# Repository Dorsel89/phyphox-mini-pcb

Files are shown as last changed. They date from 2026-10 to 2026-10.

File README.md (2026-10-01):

# phyphox:mini – PCB

KiCad project for the **phyphox:mini**, a small Bluetooth LE sensor board that
streams its measurements to the [phyphox](https://phyphox.org) app.

The design files were created with **KiCad 10**. Older KiCad versions cannot
open them.

## Hardware

| Part | Function |
|---|---|
| Nordic **nRF52832** (QFN48) | MCU with Bluetooth LE, internal DC/DC converter |
| ST **LSM6DSR** | accelerometer and gyroscope |
| Bosch **BMP580** | air pressure and temperature |
| TI **HDC1080** | relative humidity and temperature |
| Sensirion **STCC4** | CO₂ |
| Renesas/Adesto **AT25FF161A** | 16 Mbit (2 MB) SPI flash for data logging and firmware updates |
| 32 MHz and 32.768 kHz crystals | radio clock and low-power real-time clock |
| PCB antenna | 2.4 GHz, after TI application note SWRA117D |
| LED, test pads | status LED, programming and debugging (SWD) |

- 4-layer board, about 20 × 30 mm
- IMU and flash are connected via SPI; pressure, humidity and CO₂ sensors
  share one I²C bus.

## Files

| Path | Content |
|---|---|
| `Keyfob_2025_nrf52832.kicad_pro` | KiCad project |
| `Keyfob_2025_nrf52832.kicad_sch` | schematic |
| `Keyfob_2025_nrf52832.kicad_pcb` | board layout |
| `lib/` | project symbols (`*.kicad_sym`), footprints (`phyphox-footprints.pretty`) and 3D models (`3d/`) |

The project libraries are referenced relative to the project directory
(`sym-lib-table`, `fp-lib-table`), so the project opens without further setup.

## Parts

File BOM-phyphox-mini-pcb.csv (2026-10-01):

Reference | Value | Footprint | Qty | DNP | Digikey | Hersteller-Teilenummer | JLC Part | Manufacturer Part
C1 | 47uF | Capacitor_SMD:C_0805_2012Metric | 1 |  |  |  | C16780 | CL21A476MQYNNNE
C2,L1 | nc | Capacitor_SMD:C_0402_1005Metric,Inductor_SMD:L_0402_1005Metric | 2
C3,C4,C12,C13 | 12pF | Capacitor_SMD:C_0402_1005Metric | 4 |  |  |  | C526985 | CC0402GRNPO9BN120
C5,C9,C11,C14,C15 | 100nF | Capacitor_SMD:C_0402_1005Metric | 5 |  | 1276-6720-1-ND |  | C1525 | CL05B104KA5NNNC
C6 | 0.8pF NP0 5% | Capacitor_SMD:C_0402_1005Metric | 1
C7 | 4.7uF | Capacitor_SMD:C_0402_1005Metric | 1 |  | 1276-1784-1-ND |  | C23733 | CL05A475KP5NRNC
C8 | 100pF | Capacitor_SMD:C_0402_1005Metric | 1 |  | 478-1082-1-ND |  | C1546 | KGM05ACG1H101FN
C10 | 1uF | Capacitor_SMD:C_0402_1005Metric | 1 |  | 1276-1067-1-ND |  | C52923 | CL05A105KO5NNNC
C16 | 0.5pF | Capacitor_SMD:C_0402_1005Metric | 1
D1 | LED | LED_SMD:LED_0402_1005Metric | 1
L3 | 3.9nH | Inductor_SMD:L_0402_1005Metric | 1 |  |  |  | C14033 | MLG1005S3N9BT000
L4 | 15nH | Inductor_SMD:L_0402_1005Metric | 1 |  |  |  | C27143 | MLG1005S15NJT000
L5 | 10uH | Inductor_SMD:L_0603_1608Metric | 1 |  |  |  | C1035 | MLF1608E100KTD00
R1 | 1R1 | Resistor_SMD:R_0402_1005Metric | 1 |  |  |  |  | SFR01MZPJ112
R2,R3,R4,R5 | 10k | Resistor_SMD:R_0402_1005Metric | 4 |  |  |  |  | RCA040210K0JNED
TP1 | TestPoint | phyphox-footprints:MY-ZJ-128 | 1
TP5 | TestPoint | phyphox-footprints:phyfob_bat_dot | 1 | Nicht bestücken
U1 | nRF52832-QFxx | Package_DFN_QFN:QFN-48-1EP_6x6mm_P0.4mm_EP4.6x4.6mm | 1
U2 | LSM6DSRTR | phyphox-footprints:lsm6dsr | 1
U3 | BMP580 | phyphox-footprints:BMP581 | 1
U4 | HDC1080 | Package_SON:Texas_PWSON-N6 | 1
U5 | STCC4 | phyphox-footprints:STCC4 | 1
U6 | AT25FF161A | phyphox-footprints:USON-8L-2X3X0P6_MAC | 1 |  |  | MX25R1635FZUIL0
Y1 | 32MHz | Crystal:Crystal_SMD_2016-4Pin_2.0x1.6mm | 1 |  |  |  | C718072 | X201632MKB4SI
Y2 | C5185312 | Crystal:Crystal_SMD_3215-2Pin_3.2x1.5mm | 1 |  |  | C5185312

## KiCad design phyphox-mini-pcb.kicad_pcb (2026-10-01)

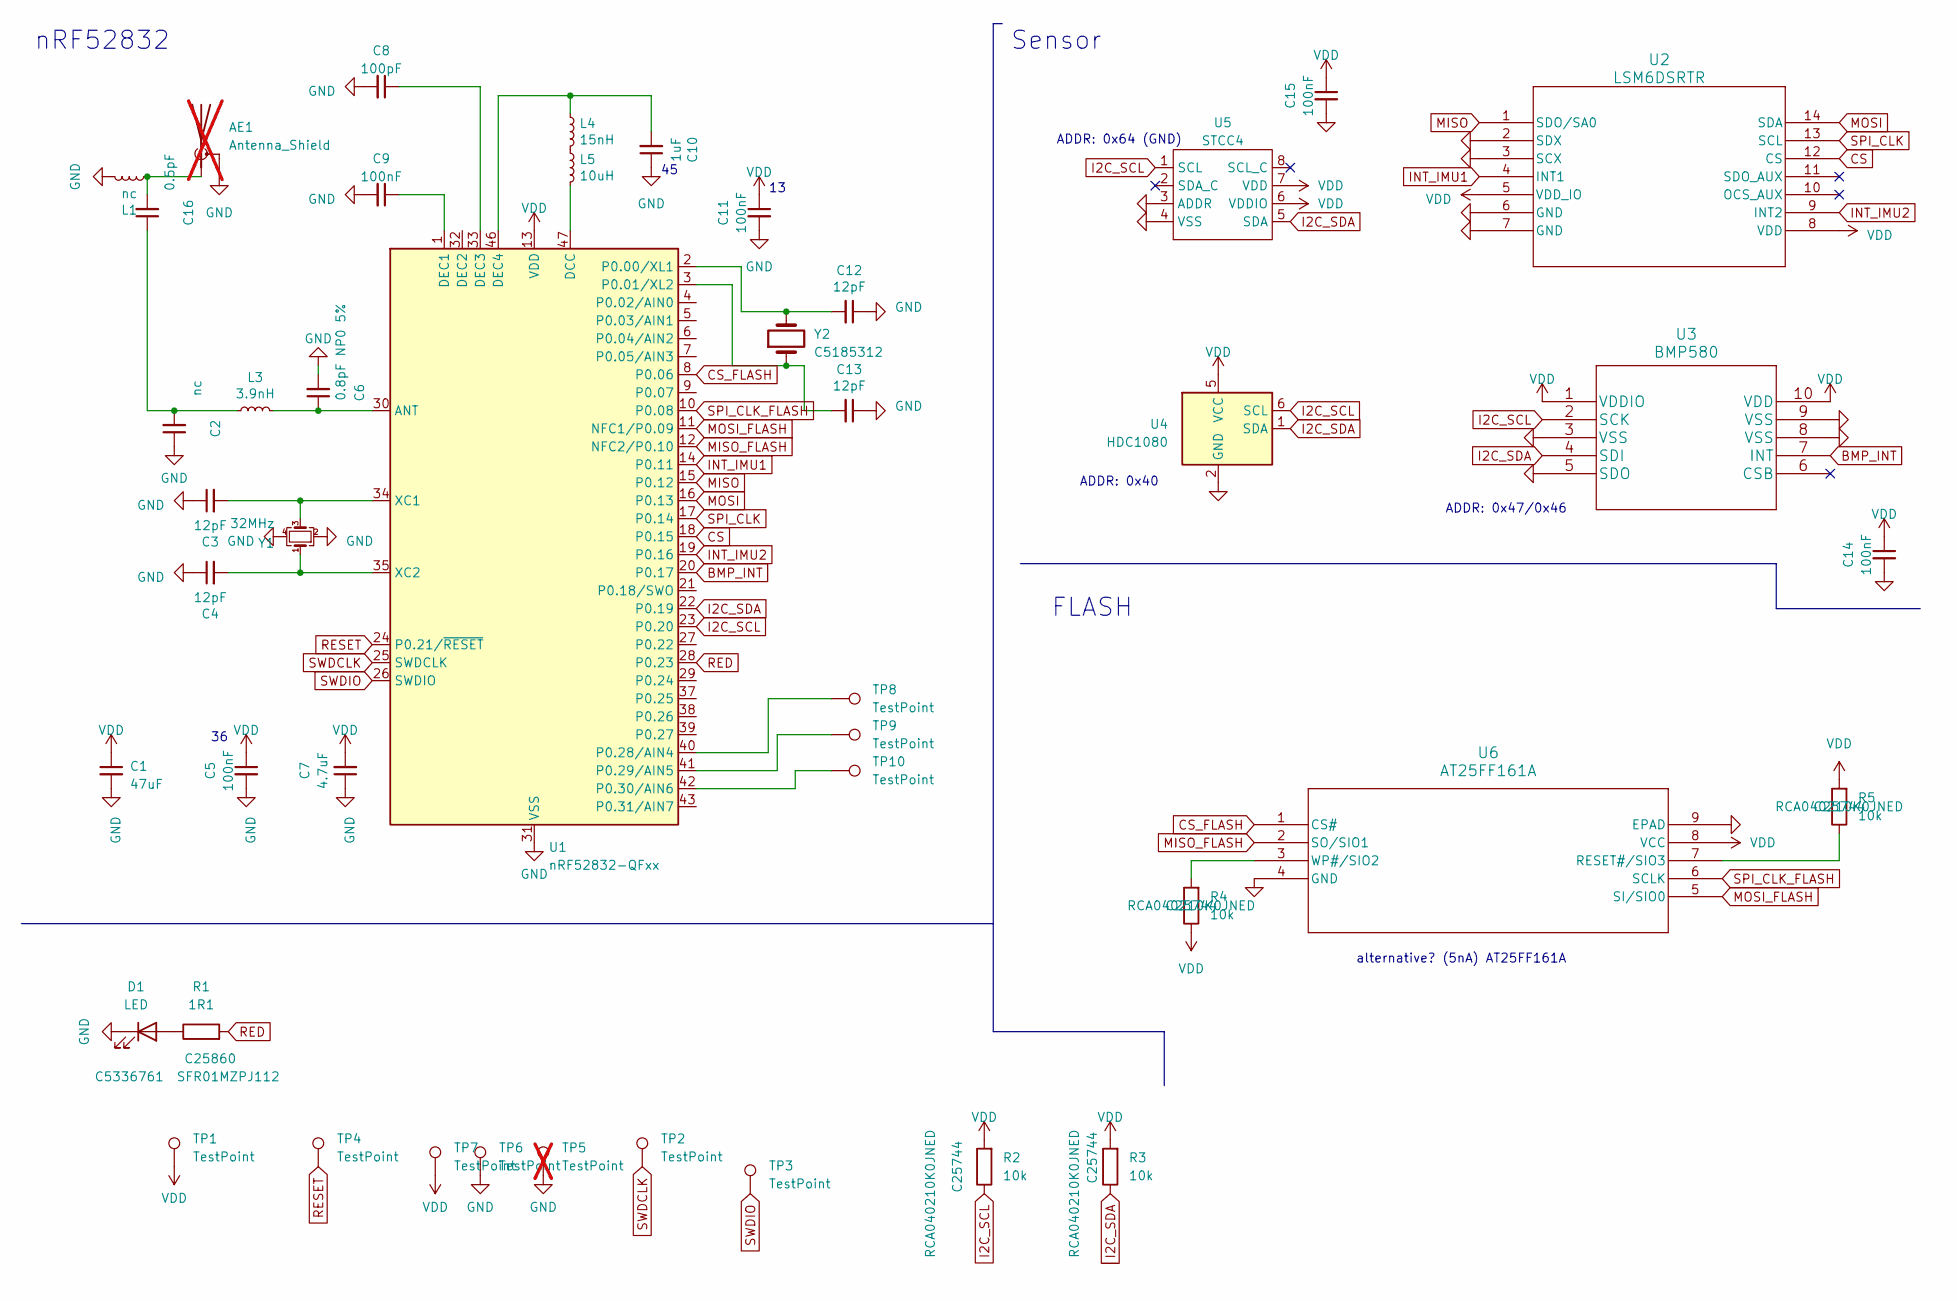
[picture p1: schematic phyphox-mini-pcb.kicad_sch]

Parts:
AE1: Antenna_Shield; Texas_SWRA117D_2.4GHz_Right; not fitted
C1: 47uF; C_0805_2012Metric; Manufacturer Part CL21A476MQYNNNE; LCSC Part C16780
C2: nc; C_0402_1005Metric
C3, C4, C12, C13: 12pF; C_0402_1005Metric; Manufacturer Part CC0402GRNPO9BN120; LCSC Part C526985
C5, C9, C11, C14, C15: 100nF; C_0402_1005Metric; Manufacturer Part CL05B104KA5NNNC; LCSC Part C307331
C6: 0.8pF NP0 5%; C_0402_1005Metric; LCSC Part C76915
C7: 4.7uF; C_0402_1005Metric; Manufacturer Part CL05A475KP5NRNC; LCSC Part C23733
C8: 100pF; C_0402_1005Metric; Manufacturer Part KGM05ACG1H101FN; LCSC Part C1546
C10: 1uF; C_0402_1005Metric; Manufacturer Part CL05A105KO5NNNC; LCSC Part C52923
C16: 0.5pF; C_0402_1005Metric; LCSC C76912
D1: LED; LED_0402_1005Metric; LCSC C5336761
L1: nc; L_0402_1005Metric
L3: 3.9nH; L_0402_1005Metric; Manufacturer Part MLG1005S3N9BT000; LCSC Part C14033
L4: 15nH; L_0402_1005Metric; Manufacturer Part MLG1005S15NJT000; LCSC Part C27143
L5: 10uH; L_0603_1608Metric; Manufacturer Part MLF1608E100KTD00; LCSC Part C1035
R1: 1R1; R_0402_1005Metric; Manufacturer Part SFR01MZPJ112; LCSC C25860
R2, R3, R4, R5: 10k; R_0402_1005Metric; Manufacturer Part RCA040210K0JNED; LCSC C25744
TP1: TestPoint; MY-ZJ-128; LCSC C5354946
TP2, TP3, TP4, TP6, TP7, TP8, TP9, TP10: TestPoint; TestPoint_Pad_D1.0mm
TP5: TestPoint; phyfob_bat_dot; not fitted
U1: nRF52832-QFxx; QFN-48-1EP_6x6mm_P0.4mm_EP4.6x4.6mm; LCSC Part C77540
U2: LSM6DSRTR; lsm6dsr; LCSC Part C784817
U3: BMP580; BMP581; LCSC Part C22391138
U4: HDC1080; Texas_PWSON-N6; LCSC Part C2864159
U5: STCC4; LCSC C49191471
U6: AT25FF161A; USON-8L-2X3X0P6_MAC; LCSC C152595
Y1: 32MHz; Crystal_SMD_2016-4Pin_2.0x1.6mm; Manufacturer Part X201632MKB4SI; LCSC Part C718072
Y2: C5185312; Crystal_SMD_3215-2Pin_3.2x1.5mm; LCSC Part C5185312

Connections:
BMP_INT: U1.20 (P0.17), U3.7 (INT)
CS: U1.18 (P0.15), U2.12 (CS)
CS_FLASH: U1.8 (P0.06), U6.1 (CS#)
GND: AE1.2 (Shield), C1.2, C2.1, C3.1, C4.1, C5.2, C6.2, C7.1, C8.2, C9.2, C10.1, C11.2, C12.1, C13.1, C14.2, C15.2, D1.1 (K), L1.2, TP5.1 (1_1), TP6.1 (1_1), U1.31 (VSS), U1.45 (VSS), U1.49 (VSS), U2.2 (SDX), U2.3 (SCX), U2.6 (GND), U2.7 (GND), U3.3 (VSS), U3.5 (SDO), U3.8 (VSS), U3.9 (VSS), U4.2 (GND), U5.3 (ADDR), U5.4 (VSS), U6.4 (GND), U6.9 (EPAD), Y1.2, Y1.4
I2C_SCL: R2.1, U1.23 (P0.20), U3.2 (SCK), U4.6 (SCL), U5.1 (SCL)
I2C_SDA: R3.1, U1.22 (P0.19), U3.4 (SDI), U4.1 (SDA), U5.5 (SDA)
INT_IMU1: U1.14 (P0.11), U2.4 (INT1)
INT_IMU2: U1.19 (P0.16), U2.9 (INT2)
MISO: U1.15 (P0.12), U2.1 (SDO/SA0)
MISO_FLASH: U1.12 (NFC2/P0.10), U6.2 (SO/SIO1)
MOSI: U1.16 (P0.13), U2.14 (SDA)
MOSI_FLASH: U1.11 (NFC1/P0.09), U6.5 (SI/SIO0)
unnamed: AE1.1 (A), C16.2, L1.1
unnamed: C2.2, C16.1, L3.1
unnamed: D1.2 (A), R1.1
unnamed: L4.2, L5.1
unnamed: C6.1, L3.2, U1.30 (ANT)
unnamed: L5.2, U1.47 (DCC)
unnamed: C9.1, U1.1 (DEC1)
unnamed: C8.1, U1.33 (DEC3)
unnamed: C10.2, L4.1, U1.46 (DEC4)
unnamed: C12.2, U1.2 (P0.00/XL1), Y2.2
unnamed: C13.2, U1.3 (P0.01/XL2), Y2.1
unnamed: TP8.1 (1_1), U1.40 (P0.28/AIN4)
unnamed: TP9.1 (1_1), U1.41 (P0.29/AIN5)
unnamed: TP10.1 (1_1), U1.42 (P0.30/AIN6)
unnamed: C3.2, U1.34 (XC1), Y1.3
unnamed: C4.2, U1.35 (XC2), Y1.1
unnamed: R5.1, U6.7 (RESET#/SIO3)
unnamed: R4.2, U6.3 (WP#/SIO2)
RED: R1.2, U1.28 (P0.23)
RESET: TP4.1 (1_1), U1.24 (P0.21/~RESET)
SPI_CLK: U1.17 (P0.14), U2.13 (SCL)
SPI_CLK_FLASH: U1.10 (P0.08), U6.6 (SCLK)
SWDCLK: TP2.1 (1_1), U1.25 (SWDCLK)
SWDIO: TP3.1 (1_1), U1.26 (SWDIO)
VDD: C1.1, C5.1, C7.2, C11.1, C14.1, C15.1, R2.2, R3.2, R4.1, R5.2, TP1.1 (1_1), TP7.1 (1_1), U1.13 (VDD), U1.36 (VDD), U1.48 (VDD), U2.5 (VDD_IO), U2.8 (VDD), U3.1 (VDDIO), U3.10 (VDD), U4.5 (VCC), U5.6 (VDDIO), U5.7 (VDD), U6.8 (VCC)

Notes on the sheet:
FLASH
ADDR: 0x47/0x46
ADDR: 0x64 (GND)
alternative? (5nA) AT25FF161A
Sensor
ADDR: 0x40
nRF52832

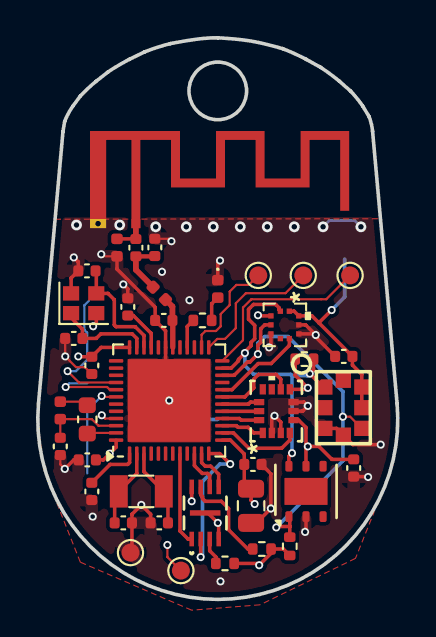
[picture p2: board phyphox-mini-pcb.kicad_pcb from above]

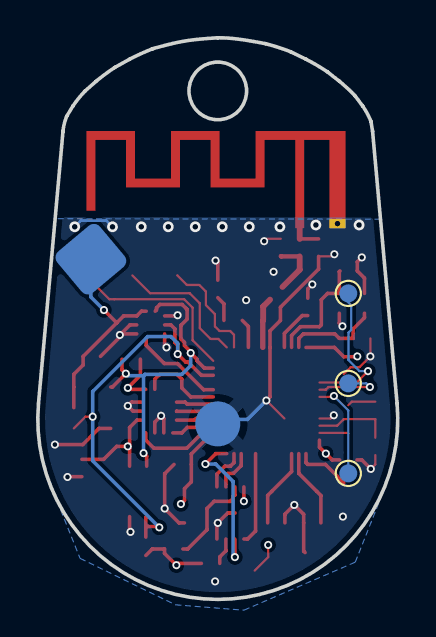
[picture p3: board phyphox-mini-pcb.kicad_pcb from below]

Board: 4 copper layers, 20.0 x 31.2 mm, 45 parts (5 on the bottom side), 37 nets.
